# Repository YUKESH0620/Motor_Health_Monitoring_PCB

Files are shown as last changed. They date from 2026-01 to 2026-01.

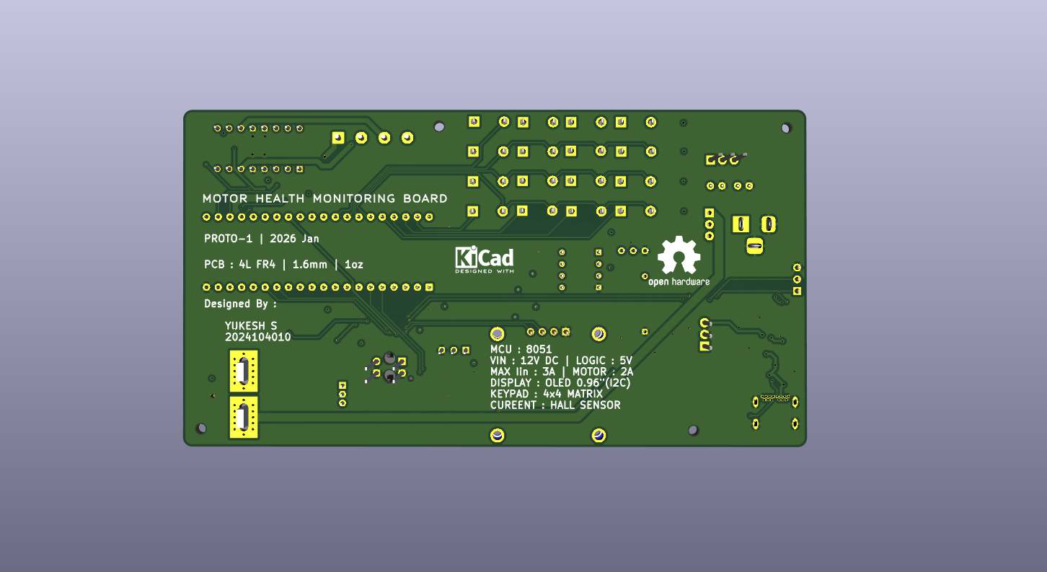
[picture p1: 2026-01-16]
HARDWARE/PCB Layout/3D View images/Screenshot 2026-01-16 144549.png

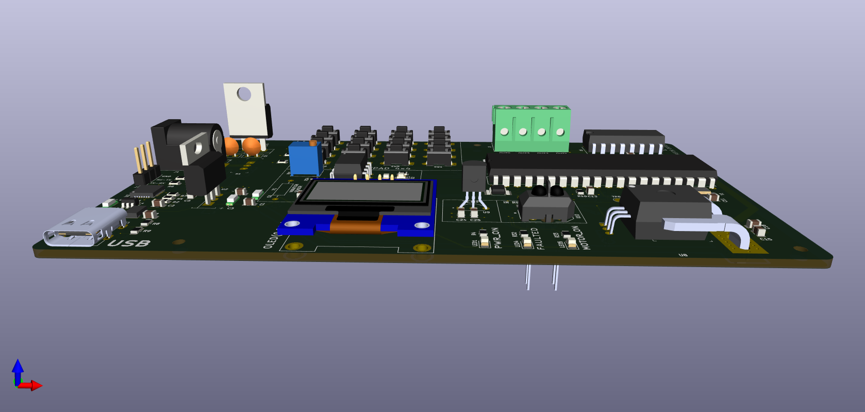
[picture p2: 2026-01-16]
HARDWARE/PCB Layout/3D View images/Screenshot 2026-01-16 144806.png

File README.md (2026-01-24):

# Motor Health Monitoring System using 8051

**Embedded Hardware–Firmware Co-Design Project**

---

## Project Overview

The **Motor Health Monitoring System** is an embedded systems project designed to monitor the operational health of an electric motor and protect it from unsafe conditions.

The project integrates:

* A structured hardware design
* Bare-metal embedded control logic
* Simulation-based validation
* Professional documentation practices

The focus is on **learning, reliability, and design clarity**, following workflows commonly used in industry and academia.

---

## System Purpose

* Monitor key motor parameters
* Detect abnormal operating conditions
* Automatically disable the motor under fault
* Provide clear visual and UART-based feedback
* Enable validation without physical hardware

---

## System Operation Flow

* System initialization

* Peripheral setup

* Sensor sampling

* Data filtering

* Threshold comparison

* Fault decision

* Motor control update

* Display & UART update

* Continuous monitoring loop

## Block Diagram

```
Power Input
    │
    V
Voltage Regulation
    │
    V
Microcontroller (8051)
 |--> Sensor Interface
 |   |--> Current
 |   |--> Temperature
 |   |--> Vibration
 |   |--> IR Sensor
 |
 |--> Motor Driver (PWM Control)
 |--> Display (OLED)
 |--> Keypad Interface
 |--> UART Debug Interface
```

---

## System Summary

| Aspect | Description |
| --- | --- |
| Controller | AT89C51 (8051 architecture) |
| Control Method | Bare-metal |
| Sensors | Current, Temperature, Vibration, IR |
| Motor Control  | PWM-based with fault shutdown |
| Display | OLED (I²C) |
| User Input | 4×4 Keypad |
| Communication  | UART |
| Validation | Proteus Simulation |
| PCB Status | Not fabricated |

---

## Design Artifacts

The repository contains:

* Complete hardware schematics

* PCB layout and 3D models (design stage)

* Proteus simulation files

* Modular firmware source code

* Structured documentation

---

# Schematic Diagram







# PCB Layout





# 3D PCB View









---

## Electrical Specifications

| Parameter | Value |
|---|---|
| Supply Voltage | 5 V DC |
| MCU Logic Level | 5 V |
| Over-Current Threshold | 15 A |
| Over-Temperature Threshold | 70 °C |
| Communication Baud Rate | Configurable (UART) |
| Fault Response Time | Deterministic (loop-based) |

---

# Simulation_v1

The system was simulated using **Proteus 8.1 Professional software** to validate firmware behavior and system-level logic prior to hardware availability.
The AT89C51 microcontroller, UART interface, motor control logic, fault indicators, and peripheral connections were instantiated according to the schematic.

## Proteus Schematic


Sensor inputs were emulated using adjustable sources to exercise overcurrent and overtemperature fault paths. UART output was used to confirm firmware execution flow and system state transitions. Motor operation was verified logically through enable signals and status indicators rather than physical motor dynamics.

Due to simulator limitations with mixed-signal SPI peripherals on the 8051 core, ADC behavior was validated at firmware logic level. Electrical accuracy of sensor interfaces is planned for validation on physical hardware.

---

## Validation Strategy

* Firmware behavior validated using Proteus simulation at system and logic level

* UART used as the primary observation and debug interface to confirm system states

* Motor control and global shutdown behavior verified through control signals and status indicators

* Fault detection, latching, and recovery logic validated against defined thresholds

* Sensor behavior emulated to exercise fault paths; ADC interface validated at firmware logic level

* Simulation limitations identified and documented; full electrical validation planned on physical hardware

* No dependency on physical PCB availability for firmware and system-level validation

---

## Repository Organization

* **Hardware**
  Contains schematic, PCB, simulation files, and hardware documentation

* **Firmware**
  Contains source code, configuration files, and firmware documentation

Each section includes its own detailed README.

---

## Current Project Status

*  Requirements defined
*  Hardware designed
*  Simulation validated
*  Firmware structured and built
*  PCB fabrication pending

---

## Future Enhancements

* Physical PCB manufacturing
* Bench testing with real motors
* Data logging and diagnostics
* IoT expansion via external gateway
* Advanced fault analytics

---

## Author

**YUKESH**
B.E. Electrical and Electronics Engineering

---

## License

This project is intended for **educational and non-commercial use**.
All materials are shared to support learning, experimentation, and academic review.

---

## Closing Note

This project demonstrates a **complete embedded system lifecycle** - from concept and schematic design to firmware integration and simulation-based validation - following practices aligned with real-world engineering workflows.

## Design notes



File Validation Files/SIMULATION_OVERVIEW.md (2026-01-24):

# Simulation Overview

## Purpose
Simulation was used to validate firmware execution, control flow,
and safety logic before hardware availability.

## Scope
* Firmware behavior verification
* Fault detection and latching logic
* Motor enable and shutdown behavior
* UART-based system observation

## Method
* Proteus schematic instantiated per design
* Sensor inputs emulated conceptually
* System behavior observed via UART and GPIO indicators

## Outcome
Simulation successfully validated system-level logic and safety behavior,
with electrical validation deferred to hardware testing.

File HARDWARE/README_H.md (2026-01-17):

# Hardware Design – Motor Health Monitoring System

## Overview

This repository documents the **complete hardware design** of the **Motor Health Monitoring System**.
The system is built around an **AT89C51 (8051) microcontroller** and integrates sensing, motor control, user interaction, communication, and power management blocks.

The hardware has been **fully designed and validated using Proteus simulation**.
At the time of writing, **no physical PCB has been fabricated**.

---

## Hardware Design Objectives

* Reliable motor parameter sensing
* Safe motor drive with immediate shutdown under fault conditions
* Deterministic digital and analog signal routing
* Modular and expandable circuit structure
* Educational clarity aligned with industry practices

---

## System-Level Hardware Architecture

The system is divided into the following functional blocks:

* Power input and regulation
* Microcontroller core
* Motor driver and PWM enable control
* Sensor interface block
* Display and user interface
* Communication and debug interface
* Status indication LEDs
* Test points for validation

---

## Power Architecture

### Power Sources

* **USB power input** (logic power and debugging)
* **External 12V input** (motor supply)

### Regulation

* **7805 Linear Voltage Regulator**

  * Input: 12V
  * Output: +5V (MCU and peripherals)
* Decoupling capacitors:

  * 0.1µF (high-frequency noise suppression)
  * 10µF (bulk stabilization)
* Capacitors placed close to the regulator and IC power pins

### Power Distribution

* +5V rail for MCU, sensors, OLED, and logic circuits
* Motor supply isolated through the motor driver
* Common ground reference across all hardware blocks

---

## Microcontroller Core

### MCU

* **AT89C51 (8051 family)**
* External **12 MHz crystal oscillator**
* RC-based reset network
* **EA pin tied HIGH** to enable internal program memory

### Key Responsibilities

* Sensor data acquisition
* Fault detection and latching
* PWM generation for motor speed control
* Display updates and UART communication
* Global motor enable/disable control

---

## Motor Driver and Control

### Motor Driver

* **L293D Dual H-Bridge Motor Driver**
* Separate logic and motor supply pins
* Internal flyback diode protection

### PWM Enable Circuit

* PWM signals generated by the MCU
* Enable pins routed via pull-up and series resistors
* Allows:

  * Speed control
  * Immediate motor shutdown during faults

### Protection Strategy

* Any detected fault disables the motor globally
* Fault condition remains latched until system reset

---

## Sensor Interface Block

### Current Sensor

* **ACS712 Hall-Effect Current Sensor**
* Measures motor current
* Analog output routed to ADC
* Used for overcurrent fault detection

### Temperature Sensor

* **LM35 Precision Temperature Sensor**
* Linear analog output (10 mV/°C)
* Used for thermal protection

### Vibration Sensor

* **SW-420 Vibration Sensor Module**
* Comparator-based digital output
* Detects abnormal mechanical vibrations

### IR Reflective Sensor

* Used for speed or object detection
* Digital output connected to MCU GPIO

---

## Analog-to-Digital Conversion

* External ADC used for analog sensor interfacing
* Supports multiple sensor channels
* SPI-like digital communication with MCU
* Improves measurement accuracy and noise immunity

---

## Display Interface

### OLED Display

* **0.96-inch SSD1306 OLED**
* I²C communication protocol
* Displays:

  * Motor status
  * Fault information
  * Sensor readings
* External pull-up resistors used on SDA and SCL lines

---

## User Interface

### Keypad

* **4×4 Matrix Keypad**
* Row-column scanning technique
* External pull-up resistors provided
* Used for:

  * Menu navigation
  * Manual reset
  * Parameter selection

---

## Communication Interfaces

### UART Debug Port

* TTL-level UART interface
* Used for:

  * Debug logging
  * Sensor monitoring
  * Fault reporting
* Compatible with USB–TTL converters

### USB Interface

* USB module used for power and communication support
* Includes basic filtering and ESD protection

---

## Status Indication LEDs

* Power ON indicator
* Motor ON indicator
* Fault indicator
* Series resistors selected to limit LED current safely

---

## Test Points and Debug Support

Dedicated test points are provided for:

* Power rails
* UART TX and RX
* PWM outputs
* Sensor signals

These enable:

* Easy probing during simulation
* Oscilloscope-based validation
* Logic analyzer connections

---

## Simulation and Validation

* Complete schematic simulated in **Proteus**
* Sensor behavior emulated
* Fault conditions injected intentionally
* UART monitored using a virtual terminal
* Motor behavior verified at logic level

---

## Design Status

*  Schematic completed
*  Proteus simulation validated
*  Electrical logic verified
*  PCB fabrication not performed

---

## Notes

This hardware design prioritizes:

* Clarity over unnecessary complexity
* Educational transparency
* Industry-relevant schematic practices
* Expandability for future enhancements

---

* **Author:** Yukesh
* **Domain:** Embedded Systems | Motor Control | Hardware–Firmware Co-Design
* **Target MCU:** AT89C51 (8051 Family)

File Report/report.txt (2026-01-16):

Plotted to 'C:\KiCad\Motor_Health_Monitoring005\Motor_Health_Monitoring_PCB-F_Cu.gbr'.
Plotted to 'C:\KiCad\Motor_Health_Monitoring005\Motor_Health_Monitoring_PCB-In1_Cu.gbr'.
Plotted to 'C:\KiCad\Motor_Health_Monitoring005\Motor_Health_Monitoring_PCB-In2_Cu.gbr'.
Plotted to 'C:\KiCad\Motor_Health_Monitoring005\Motor_Health_Monitoring_PCB-B_Cu.gbr'.
Plotted to 'C:\KiCad\Motor_Health_Monitoring005\Motor_Health_Monitoring_PCB-F_Paste.gbr'.
Plotted to 'C:\KiCad\Motor_Health_Monitoring005\Motor_Health_Monitoring_PCB-B_Paste.gbr'.
Plotted to 'C:\KiCad\Motor_Health_Monitoring005\Motor_Health_Monitoring_PCB-F_Silkscreen.gbr'.
Plotted to 'C:\KiCad\Motor_Health_Monitoring005\Motor_Health_Monitoring_PCB-B_Silkscreen.gbr'.
Plotted to 'C:\KiCad\Motor_Health_Monitoring005\Motor_Health_Monitoring_PCB-F_Mask.gbr'.
Plotted to 'C:\KiCad\Motor_Health_Monitoring005\Motor_Health_Monitoring_PCB-B_Mask.gbr'.
Plotted to 'C:\KiCad\Motor_Health_Monitoring005\Motor_Health_Monitoring_PCB-Edge_Cuts.gbr'.
Created Gerber job file 'C:\KiCad\Motor_Health_Monitoring005\Motor_Health_Monitoring_PCB-job.gbrjob'.
Info: Done.
Info: Done.

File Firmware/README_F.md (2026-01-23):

# Motor Health Monitoring System – Firmware

## Overview

This firmware is developed for an 8051-based Motor Health Monitoring System.

It monitors motor current and temperature, controls motor operation via PWM,

and provides fault protection with UART, keypad, and OLED interfaces.

The firmware is designed to be **hardware-independent during development**

and supports **simulation-based validation** prior to PCB manufacturing.

---

## Features

- Motor control using PWM

- Overcurrent and overtemperature protection

- Fault latch mechanism

- UART command interface

- 4×4 keypad control

- OLED (SSD1306) display support

- Simulation mode for pre-hardware testing

---

## Firmware Architecture

Firmware/

|--> Core/ --> main loop, system init

|--> Drivers/ --> UART, ADC, Timer, PWM, GPIO, Keypad

|--> Application/ --> motor state, fault logic, command handling

|--> Middleware/ --> OLED driver

|--> Utils/ --> filtering, delay, numeric print helpers

|--> Config/ --> pin and threshold configuration

|--> Debug/ --> reserved for logging (currently empty)

|--> Docs/ --> flowchart, protocol, fault table

|--> sdcc\_build/ --> SDCC build scripts

---

## System States

- **IDLE**  : Motor stopped, safe state

- **RUN**   : Motor running with PWM control

- **FAULT** : Motor disabled due to fault (latched)

---

## Build Environment

- Compiler: SDCC (mcs51)

- Target MCU: AT89C51

- Build Method: `build.bat`

- Output: `motor\_health\_fw.ihx`

---

## Simulation Mode

This firmware supports simulation mode to validate logic without hardware.

Simulated features:

- ADC values

- Fault injection

- UART command handling

- OLED content updates

This allows full firmware validation before PCB manufacturing.

---

## Reserved Hardware Signals

The IR sensor output and vibration sensor digital output are present
in the hardware design but intentionally unused in firmware v1.0.
They are reserved for future safety and diagnostic enhancements.

These signals are not part of the current fault detection logic
to avoid false triggers and ensure deterministic motor protection.

---

## Notes

- Hardware testing will be performed after PCB fabrication

- Firmware is structured for easy extension and maintenance

- Code is written to be portable and standards-compliant

---

## Author

Motor Health Monitoring System  

Firmware by Yukesh

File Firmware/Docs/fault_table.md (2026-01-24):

## FAULT TABLE - MOTOR HEALTH MONITORING SYSTEM
```
----------------------------------------------------------
Fault Name        : Overcurrent (OC)
Sensor            : ACS770
Threshold         : 15 A
Detection Type    : Instantaneous
Latch             : YES
Recovery          : RESET command / RESET key
Action Taken      :
  - Motor PWM disabled
  - Fault LED ON
  - System state = FAULT
----------------------------------------------------------

----------------------------------------------------------
Fault Name        : Overtemperature (OT)
Sensor            : LM35
Threshold         : 70 °C
Detection Type    : Instantaneous
Latch             : YES
Recovery          : RESET command / RESET key
Action Taken      :
  - Motor PWM disabled
  - Fault LED ON
  - System state = FAULT
----------------------------------------------------------
```
----------------------------------------------------------
Reserved Signals (Not Used in v1.0)
----------------------------------------------------------
IR sensor digital output and vibration sensor D0 output
are present in hardware but are not used for fault detection
in firmware v1.0.

Reason:
- Digital vibration thresholds are noisy
- IR detection is application-dependent
- Current and temperature provide deterministic protection

These signals are reserved for future diagnostic features.

----------------------------------------------------------
Global Fault Behavior
----------------------------------------------------------
- Fault is global (single current sensor)
- Both motors are disabled on any fault
- Fault remains latched until RESET
- START command ignored during FAULT state
----------------------------------------------------------

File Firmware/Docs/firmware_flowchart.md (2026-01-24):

```
POWER ON / RESET
        |
        v
System_Init()
GPIO_Init()
Timer_Init()
UART_Init()
PWM_Init()
Keypad_Init()
OLED_Init()
        |
        v
STATE = IDLE
Motor PWM = 0%
Fault_Latched = NO
        |
        v
---------------- MAIN LOOP ----------------
        |
        v
UART_RX_Process()
Keypad_Scan()
        |
        v
Is START command / key pressed?
        |
       YES
        |
        v
Is Fault_Latched?
        |
       NO
        |
        v
STATE = RUN
Motor PWM = Last_Set_Value
        |
        v
------------------------------------------
        |
        v
Read Sensors
(ADC Current, ADC Temperature)
        |
        v
Convert ADC -> Voltage
Convert Voltage -> Physical Units
        |
        v
Check Fault Conditions
(Current > OC_LIMIT?)
(Temperature > OT_LIMIT?)
        |
        v
If FAULT DETECTED
        |
        v
Fault_Latched = YES
STATE = FAULT
Motor PWM = 0%
Fault LED = ON
        |
        v
------------------------------------------
        |
        v
If RESET command / key pressed
        |
        v
Clear Fault_Latched
STATE = IDLE
Motor PWM = 0%
        |
        v
------------------------------------------
        |
        v
Update OLED Display
(State, PWM %, Current, Temp)
        |
        v
Repeat MAIN LOOP

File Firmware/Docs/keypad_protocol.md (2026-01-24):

## KEYPAD PROTOCOL – MOTOR HEALTH MONITORING SYSTEM

- Keypad Type : 4 × 4 Matrix Keypad
- Interface   : GPIO (Row–Column Scanning)
- MCU         : AT89C51

--------------------------------------------------
HARDWARE CONNECTION
--------------------------------------------------

Rows (Outputs):
```
 R1 → P0.0
 R2 → P0.1
 R3 → P0.2
 R4 → P0.3
```
Columns (Inputs with pull-up resistors):
```
 C1 → P0.4
 C2 → P0.5
 C3 → P0.6
 C4 → P0.7
```
Active Logic:
- Columns are pulled HIGH by resistors
- Key press pulls corresponding column LOW
- Row driven LOW sequentially during scan

--------------------------------------------------
KEY FUNCTION MAPPING
--------------------------------------------------

Key numbering follows logical order returned by firmware
(1 to 16).

Row 1:
--------------------------------------------------
```
Key 1  | START MOTOR
Key 2  | STOP MOTOR
Key 3  | RESET FAULT
Key 4  | EMERGENCY STOP
```
Row 2:
--------------------------------------------------
```
Key 5  | PWM +5%
Key 6  | PWM −5%
Key 7  | PWM +10%
Key 8  | PWM −10%
```
Row 3:
--------------------------------------------------
```
Key 9  | PWM = 25%
Key 10 | PWM = 50%
Key 11 | PWM = 75%
Key 12 | PWM = 100%
```
Row 4:
--------------------------------------------------
```
Key 13 | Reserved (Future use)
Key 14 | Reserved (Future use)
Key 15 | Reserved (Future use)
Key 16 | Reserved (Future use)
```
--------------------------------------------------
FUNCTIONAL RULES
--------------------------------------------------

- START is ignored if a fault is latched
- RESET clears fault latch and returns system to IDLE
- PWM keys are effective only in RUN state
- EMERGENCY STOP immediately disables motor PWM
- Fault state overrides all keypad inputs except RESET

--------------------------------------------------
DEBOUNCE POLICY
--------------------------------------------------

- Software debounce implemented
- Key must be released before next detection
- Long press is treated as single press

--------------------------------------------------
NOTES
--------------------------------------------------

- Keypad control and UART control operate in parallel
- Both interfaces follow the same state machine rules
- Keypad is intended for local/manual control

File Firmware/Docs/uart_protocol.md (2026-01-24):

## UART PROTOCOL - MOTOR HEALTH MONITORING SYSTEM
```
Baud Rate   : 9600
Data Bits   : 8
Parity      : None
Stop Bits   : 1
Line Ending : LF (\n)
Case        : Case-insensitive
Echo        : Enabled
```
-----------------------------------------
COMMAND LIST
-----------------------------------------

START
- Action: Start motor
- Condition: Only if no fault is latched
- Response: OK:RUN

STOP
- Action: Stop motor
- Response: OK:IDLE

RESET
- Action: Clear fault latch and go to IDLE
- Response: OK:RESET

PWM <0–100>
- Action: Set PWM duty cycle percentage
- Example: PWM 60
- Response: OK:PWM=60

STATUS
- Action: Report current system status
- Response Format:
  ```
  STATE=<IDLE/RUN/FAULT>
  PWM=<value>
  I=<current_A>
  T=<temperature_C>
  ```
-----------------------------------------
ERROR RESPONSES
-----------------------------------------

- ERR:FAULT_ACTIVE
- ERR:INVALID_CMD
- ERR:OUT_OF_RANGE

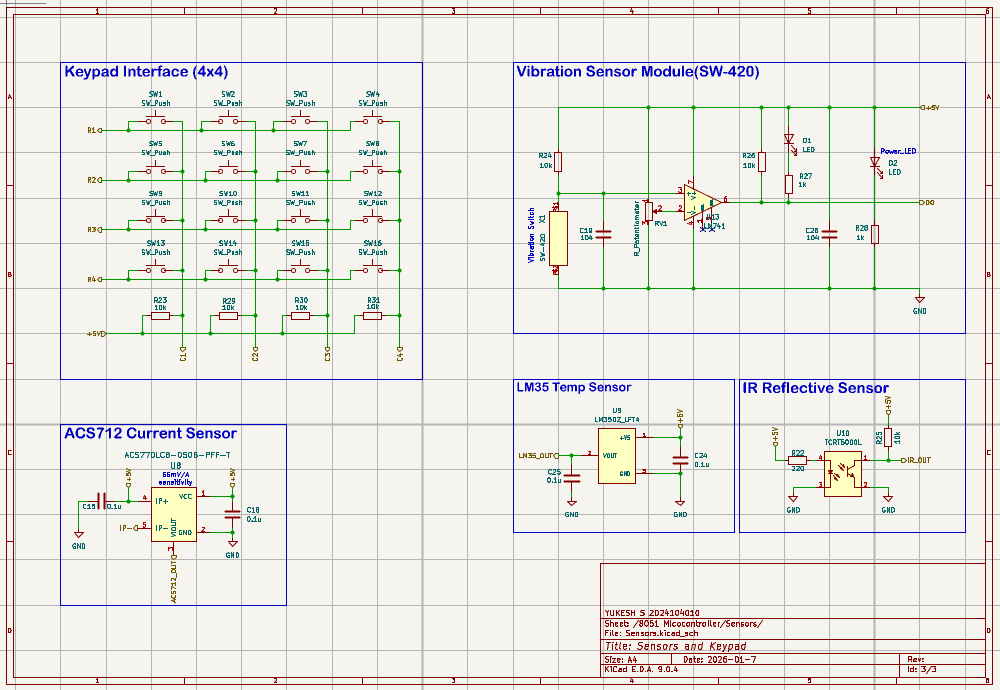
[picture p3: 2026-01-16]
Images/Schematic images/Screenshot 2026-01-11 205225.png

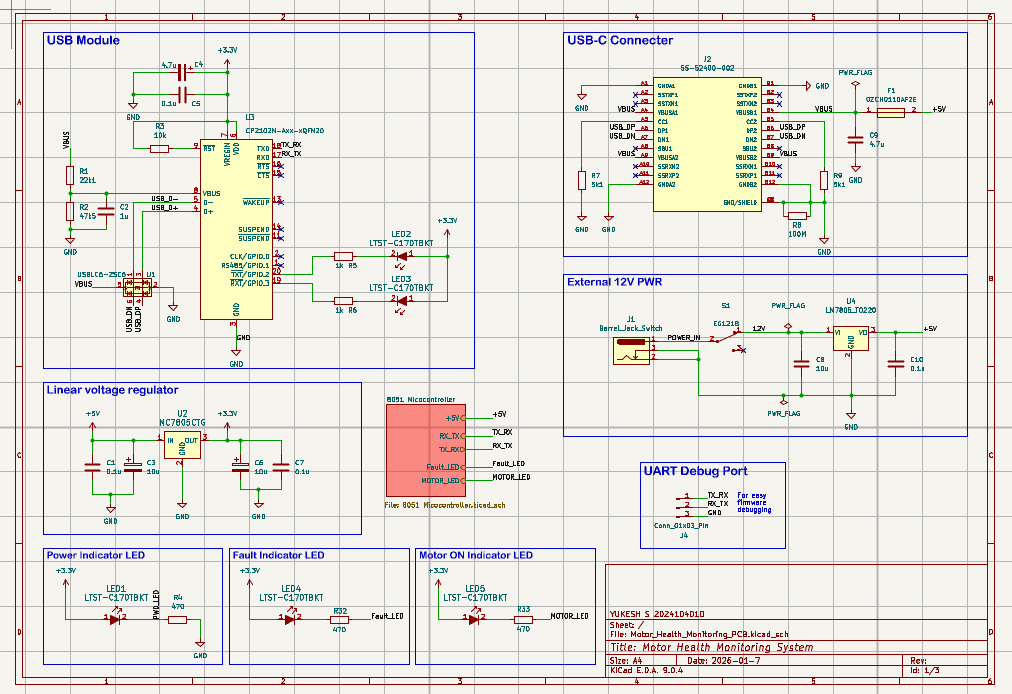
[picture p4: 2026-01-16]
Images/Schematic images/Screenshot 2026-01-11 205045 - Copy.png

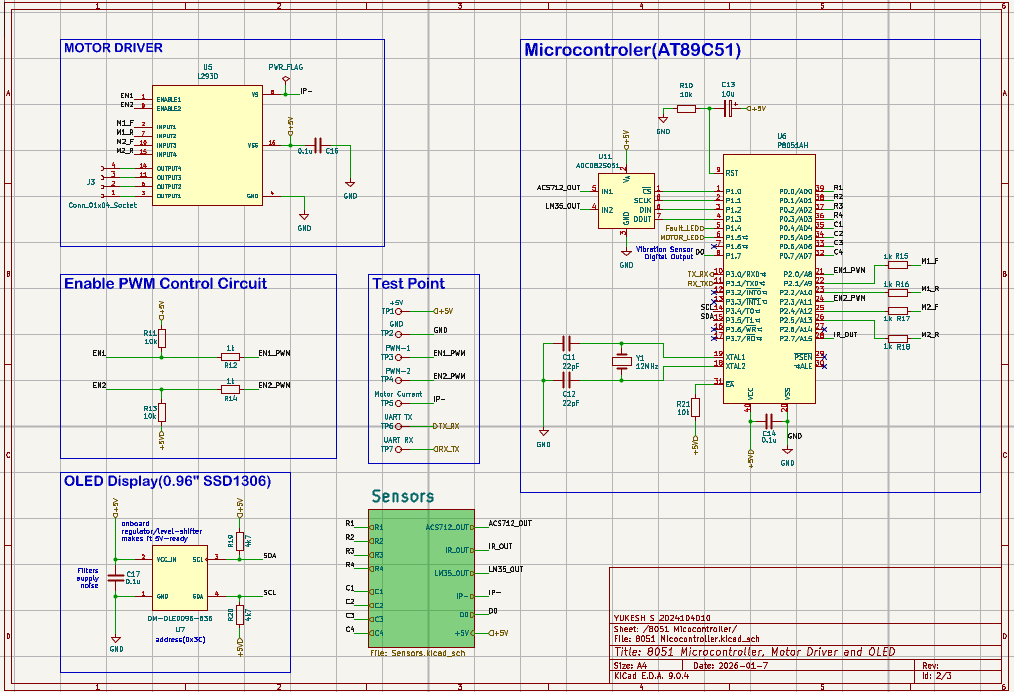
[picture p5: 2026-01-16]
Images/Schematic images/Screenshot 2026-01-11 205103 - Copy (2).png

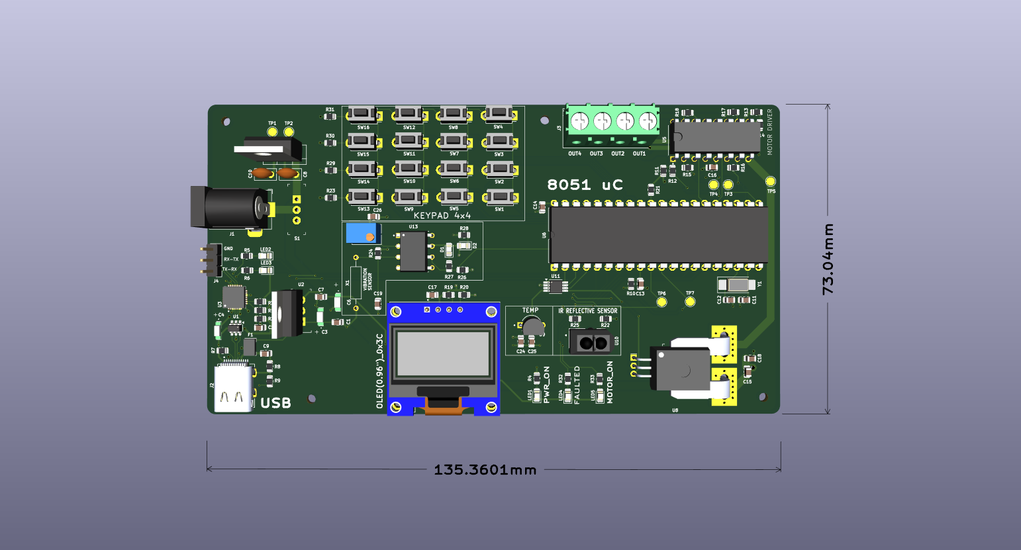
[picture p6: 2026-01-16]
HARDWARE/PCB Layout/3D View images/Screenshot 2026-01-16 144525.png

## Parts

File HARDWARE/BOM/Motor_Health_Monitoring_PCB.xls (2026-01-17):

Reference | Value | Qty | Description | Footprint | Purpose | Datasheet
C1 | 0.1u | 1 | Unpolarized capacitor | Capacitor_SMD:C_0805_2012Metric |  | ~
C2 | 1u | 1 | Unpolarized capacitor | Capacitor_SMD:C_0805_2012Metric |  | ~
C3 | 10u | 1 | Polarized capacitor | Esp-32_sensor_Board004_Footprints:T491A |  | ~
C4 | 4.7u | 1 | Polarized capacitor | Esp-32_sensor_Board004_Footprints:T491A |  | ~
C5 | 0.1u | 1 | Unpolarized capacitor | Capacitor_SMD:C_0805_2012Metric |  | ~
C6 | 10u | 1 | Polarized capacitor | Esp-32_sensor_Board004_Footprints:T491A |  | ~
C7 | 0.1u | 1 | Unpolarized capacitor | Capacitor_SMD:C_0805_2012Metric |  | ~
C8 | 10u | 1 | Unpolarized capacitor | Capacitor_THT:C_Disc_D5.0mm_W2.5mm_P2.50mm |  | ~
C9 | 4.7u | 1 | Unpolarized capacitor | Capacitor_SMD:C_0805_2012Metric |  | ~
C10 | 0.1u | 1 | Unpolarized capacitor | Capacitor_THT:C_Disc_D5.0mm_W2.5mm_P2.50mm |  | ~
C11 | 22pF | 1 | Unpolarized capacitor | Capacitor_SMD:C_0805_2012Metric |  | ~
C12 | 22pF | 1 | Unpolarized capacitor | Capacitor_SMD:C_0805_2012Metric |  | ~
C13 | 10u | 1 | Polarized capacitor | Capacitor_SMD:C_0805_2012Metric |  | ~
C14 | 0.1u | 1 | Unpolarized capacitor | Capacitor_SMD:C_0805_2012Metric |  | ~
C15 | 0.1u | 1 | Unpolarized capacitor | Capacitor_SMD:C_0805_2012Metric |  | ~
C16 | 0.1u | 1 | Unpolarized capacitor | Capacitor_SMD:C_0805_2012Metric |  | ~
C17 | 0.1u | 1 | Unpolarized capacitor | Capacitor_SMD:C_0805_2012Metric |  | ~
C18 | 0.1u | 1 | Unpolarized capacitor | Capacitor_SMD:C_0805_2012Metric |  | ~
C19 | 104 | 1 | Unpolarized capacitor | Capacitor_SMD:C_0805_2012Metric |  | ~
C24 | 0.1u | 1 | Unpolarized capacitor | Capacitor_SMD:C_0805_2012Metric |  | ~
C25 | 0.1u | 1 | Unpolarized capacitor | Capacitor_SMD:C_0805_2012Metric |  | ~
C26 | 104 | 1 | Unpolarized capacitor | Capacitor_SMD:C_0805_2012Metric |  | ~
D1 | LED | 1 | Light emitting diode | LED_SMD:LED_0805_2012Metric_Pad1.15x1.40mm_HandSolder |  | ~
D2 | LED | 1 | Light emitting diode | LED_SMD:LED_0805_2012Metric_Pad1.15x1.40mm_HandSolder |  | ~
F1 | 0ZCH0110AF2E | 1 | 1210 SMT PPTC | 1.10 Ih | 16V | Esp-32_sensor_Board004_Footprints:FUSC3226X100N |  | https://www.belfuse.com/resources/datasheets/circuitprotection/ds-cp-0zch-series.pdf
J1 | Barrel_Jack_Switch | 1 | DC Barrel Jack with an internal switch | Connector_BarrelJack:BarrelJack_Horizontal |  | ~
J2 | SS-52400-002 | 1 | USB-C Connector | Esp-32_sensor_Board004_Footprints:BELFUSE_SS-52400-002
J3 | Conn_01x04_Socket | 1 | Generic connector, single row, 01x04, script generated | Connector_PinHeader_2.54mm:PinHeader_1x04_P2.54mm_Horizontal |  | ~
J4 | Conn_01x03_Pin | 1 | Generic connector, single row, 01x03, script generated | Connector_PinHeader_2.54mm:PinHeader_1x03_P2.54mm_Horizontal |  | ~
LED1 | LTST-C170TBKT | 1 | LED BLUE CLEAR SMD | LED_SMD:LED_0805_2012Metric_Pad1.15x1.40mm_HandSolder |  | http://optoelectronics.liteon.com/upload/download/DS-22-99-0226/LTST-C170TBKT.pdf
LED2 | LTST-C170TBKT | 1 | LED BLUE CLEAR SMD | LED_SMD:LED_0805_2012Metric_Pad1.15x1.40mm_HandSolder |  | http://optoelectronics.liteon.com/upload/download/DS-22-99-0226/LTST-C170TBKT.pdf
LED3 | LTST-C170TBKT | 1 | LED BLUE CLEAR SMD | LED_SMD:LED_0805_2012Metric_Pad1.15x1.40mm_HandSolder |  | http://optoelectronics.liteon.com/upload/download/DS-22-99-0226/LTST-C170TBKT.pdf
LED4 | LTST-C170TBKT | 1 | LED BLUE CLEAR SMD | LED_SMD:LED_0805_2012Metric_Pad1.15x1.40mm_HandSolder |  | http://optoelectronics.liteon.com/upload/download/DS-22-99-0226/LTST-C170TBKT.pdf
LED5 | LTST-C170TBKT | 1 | LED BLUE CLEAR SMD | LED_SMD:LED_0805_2012Metric_Pad1.15x1.40mm_HandSolder |  | http://optoelectronics.liteon.com/upload/download/DS-22-99-0226/LTST-C170TBKT.pdf
R1 | 22k1 | 1 | Resistor | Resistor_SMD:R_0805_2012Metric |  | ~
R2 | 47k5 | 1 | Resistor | Resistor_SMD:R_0805_2012Metric |  | ~
R3 | 10k | 1 | Resistor | Resistor_SMD:R_0805_2012Metric |  | ~
R4 | 470 | 1 | Resistor | Resistor_SMD:R_0805_2012Metric |  | ~
R5 | 1k | 1 | Resistor | Resistor_SMD:R_0805_2012Metric |  | ~
R6 | 1k | 1 | Resistor | Resistor_SMD:R_0805_2012Metric |  | ~
R7 | 5k1 | 1 | Resistor | Resistor_SMD:R_0805_2012Metric |  | ~
R8 | 100M | 1 | Resistor | Resistor_SMD:R_0805_2012Metric |  | ~
R9 | 5k1 | 1 | Resistor | Resistor_SMD:R_0805_2012Metric |  | ~
R10 | 10k | 1 | Resistor | Resistor_SMD:R_0805_2012Metric |  | ~
R11 | 10k | 1 | Resistor | Resistor_SMD:R_0805_2012Metric |  | ~
R12 | 1k | 1 | Resistor | Resistor_SMD:R_0805_2012Metric |  | ~
R13 | 10k | 1 | Resistor | Resistor_SMD:R_0805_2012Metric |  | ~
R14 | 1k | 1 | Resistor | Resistor_SMD:R_0805_2012Metric |  | ~
R15 | 1k | 1 | Resistor | Resistor_SMD:R_0805_2012Metric |  | ~
R16 | 1k | 1 | Resistor | Resistor_SMD:R_0805_2012Metric |  | ~
R17 | 1k | 1 | Resistor | Resistor_SMD:R_0805_2012Metric |  | ~
R18 | 1k | 1 | Resistor | Resistor_SMD:R_0805_2012Metric |  | ~
R19 | 4k7 | 1 | Resistor | Resistor_SMD:R_0805_2012Metric |  | ~
R20 | 4k7 | 1 | Resistor | Resistor_SMD:R_0805_2012Metric |  | ~
R21 | 10k | 1 | Resistor | Resistor_SMD:R_0805_2012Metric |  | ~
R22 | 220 | 1 | Resistor | Resistor_SMD:R_0805_2012Metric |  | ~
R23 | 10k | 1 | Resistor | Resistor_SMD:R_0805_2012Metric |  | ~
R24 | 10k | 1 | Resistor | Resistor_SMD:R_0805_2012Metric |  | ~
R25 | 10k | 1 | Resistor | Resistor_SMD:R_0805_2012Metric |  | ~
R26 | 10k | 1 | Resistor | Resistor_SMD:R_0805_2012Metric |  | ~
R27 | 1k | 1 | Resistor | Resistor_SMD:R_0805_2012Metric |  | ~
R28 | 1k | 1 | Resistor | Resistor_SMD:R_0805_2012Metric |  | ~
R29 | 10k | 1 | Resistor | Resistor_SMD:R_0805_2012Metric |  | ~
R30 | 10k | 1 | Resistor | Resistor_SMD:R_0805_2012Metric |  | ~
R31 | 10k | 1 | Resistor | Resistor_SMD:R_0805_2012Metric |  | ~
R32 | 470 | 1 | Resistor | Resistor_SMD:R_0805_2012Metric |  | ~
R33 | 470 | 1 | Resistor | Resistor_SMD:R_0805_2012Metric |  | ~
RV1 | R_Potentiometer | 1 | Potentiometer | Potentiometer_THT:Potentiometer_Bourns_3266Y_Vertical |  | ~
S1 | EG1218 | 1 | SWITCH SLIDE SPDT 200MA 30V | digikey-footprints:Switch_Slide_11.6x4mm_EG1218 |  | http://spec_sheets.e-switch.com/specs/P040040.pdf
SW1 | SW_Push | 1 | Push button switch, generic, two pins | Button_Switch_THT:SW_PUSH_1P1T_6x3.5mm_H5.0_APEM_MJTP1250 |  | ~
SW2 | SW_Push | 1 | Push button switch, generic, two pins | Button_Switch_THT:SW_PUSH_1P1T_6x3.5mm_H5.0_APEM_MJTP1250 |  | ~
SW3 | SW_Push | 1 | Push button switch, generic, two pins | Button_Switch_THT:SW_PUSH_1P1T_6x3.5mm_H5.0_APEM_MJTP1250 |  | ~
SW4 | SW_Push | 1 | Push button switch, generic, two pins | Button_Switch_THT:SW_PUSH_1P1T_6x3.5mm_H5.0_APEM_MJTP1250 |  | ~
SW5 | SW_Push | 1 | Push button switch, generic, two pins | Button_Switch_THT:SW_PUSH_1P1T_6x3.5mm_H5.0_APEM_MJTP1250 |  | ~
SW6 | SW_Push | 1 | Push button switch, generic, two pins | Button_Switch_THT:SW_PUSH_1P1T_6x3.5mm_H5.0_APEM_MJTP1250 |  | ~
SW7 | SW_Push | 1 | Push button switch, generic, two pins | Button_Switch_THT:SW_PUSH_1P1T_6x3.5mm_H5.0_APEM_MJTP1250 |  | ~
SW8 | SW_Push | 1 | Push button switch, generic, two pins | Button_Switch_THT:SW_PUSH_1P1T_6x3.5mm_H5.0_APEM_MJTP1250 |  | ~
SW9 | SW_Push | 1 | Push button switch, generic, two pins | Button_Switch_THT:SW_PUSH_1P1T_6x3.5mm_H5.0_APEM_MJTP1250 |  | ~
SW10 | SW_Push | 1 | Push button switch, generic, two pins | Button_Switch_THT:SW_PUSH_1P1T_6x3.5mm_H5.0_APEM_MJTP1250 |  | ~
SW11 | SW_Push | 1 | Push button switch, generic, two pins | Button_Switch_THT:SW_PUSH_1P1T_6x3.5mm_H5.0_APEM_MJTP1250 |  | ~
SW12 | SW_Push | 1 | Push button switch, generic, two pins | Button_Switch_THT:SW_PUSH_1P1T_6x3.5mm_H5.0_APEM_MJTP1250 |  | ~
SW13 | SW_Push | 1 | Push button switch, generic, two pins | Button_Switch_THT:SW_PUSH_1P1T_6x3.5mm_H5.0_APEM_MJTP1250 |  | ~
SW14 | SW_Push | 1 | Push button switch, generic, two pins | Button_Switch_THT:SW_PUSH_1P1T_6x3.5mm_H5.0_APEM_MJTP1250 |  | ~
SW15 | SW_Push | 1 | Push button switch, generic, two pins | Button_Switch_THT:SW_PUSH_1P1T_6x3.5mm_H5.0_APEM_MJTP1250 |  | ~
SW16 | SW_Push | 1 | Push button switch, generic, two pins | Button_Switch_THT:SW_PUSH_1P1T_6x3.5mm_H5.0_APEM_MJTP1250 |  | ~
TP1 | +5V | 1 | test point | TestPoint:TestPoint_Bridge_Pitch2.54mm_Drill1.3mm |  | ~
TP2 | GND | 1 | test point | TestPoint:TestPoint_Bridge_Pitch2.54mm_Drill1.3mm |  | ~
TP3 | PWM-1 | 1 | test point | TestPoint:TestPoint_Bridge_Pitch2.54mm_Drill1.3mm |  | ~
TP4 | PWM-2 | 1 | test point | TestPoint:TestPoint_Bridge_Pitch2.54mm_Drill1.3mm |  | ~
TP5 | Motor Current | 1 | test point | TestPoint:TestPoint_Bridge_Pitch2.54mm_Drill1.3mm |  | ~
TP6 | UART TX | 1 | test point | TestPoint:TestPoint_Bridge_Pitch2.54mm_Drill1.3mm |  | ~
TP7 | UART RX | 1 | test point | TestPoint:TestPoint_Bridge_Pitch2.54mm_Drill1.3mm |  | ~
U1 | USBLC6-2SC6 | 1 | Very low capacitance ESD protection diode, 2 data-line, SOT-23-6 | Package_TO_SOT_SMD:SOT-23-6 |  | https://www.st.com/resource/en/datasheet/usblc6-2.pdf
U2 | MC7805CTG | 1 | IC REG LINEAR 5V 1A TO220AB | digikey-footprints:TO-220-3 |  | http://www.onsemi.com/pub/Collateral/MC7800-D.PDF
U3 | CP2102N-Axx-xQFN20 | 1 | USB to UART master bridge, QFN-20 | Footprints:QFN50P500X500X100-29N |  | https://www.silabs.com/documents/public/data-sheets/cp2102n-datasheet.pdf
U4 | LM7805_TO220 | 1 | Positive 1A 35V Linear Regulator, Fixed Output 5V, TO-220 | Package_TO_SOT_THT:TO-220-3_Vertical |  | https://www.onsemi.cn/PowerSolutions/document/MC7800-D.PDF
U5 | L293D | 1 | Motor Driver 2 Channel | Footprints:DIP880W50P254L2000H510Q16
U6 | P8051AH | 1 | MCS-51 8-bit Control-Oriented Microcontrollers, 4K x 8 masked ROM, 128 x 8 RAM, 2x 16-bit timers / event counters, 12MHz, DIP-40 | Package_DIP:DIP-40_W15.24mm |  | https://www.datasheetarchive.com/datasheet/MCS%2051/Intel
U7 | DM-OLED096-636 | 1 | OLED Display( 0.96" ) | Footprints:MODULE_DM-OLED096-636
U8 | ACS770LCB-050B-PFF-T | 1 | SENSOR CURRENT HALL 50A AC/DC | digikey-footprints:CB-5_Formed_Leads |  | https://www.allegromicro.com/~/media/Files/Datasheets/ACS770-Datasheet.pdf
U9 | LM35DZ_LFT4 | 1 | Temperature Sensor | Footprints:IC_LM35DZ_LFT4
U10 | TCRT5000L | 1 | IR Reflection Detector | Footprints:XDCR_TCRT5000L
U11 | ADC082S051 | 1 | 2 channel, 200 - 500 ksps, 8-bit ADC, 2.7 - 5.25V supply, TSSOP-8 (MSOP-8, Texas VSSOP-8) | Package_SO:VSSOP-8_3x3mm_P0.65mm |  | https://www.ti.com/lit/ds/symlink/adc082s051.pdf
U13 | LM741 | 1 | Operational Amplifier, DIP-8/TO-99-8 | Footprints:DIP794W45P254L959H508Q8 |  | http://www.ti.com/lit/ds/symlink/lm741.pdf
X1 | SW-420 | 1 | Vibration sensor | Footprints:SW-420
Y1 | 12MHz | 1 | Two pin crystal | Crystal:Crystal_SMD_5032-2Pin_5.0x3.2mm_HandSoldering |  | ~

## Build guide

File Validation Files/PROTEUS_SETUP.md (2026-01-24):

# Proteus Setup

## Simulation Tool
* Proteus 8.1 Professional used for system-level simulation

## Core Components
* AT89C51 microcontroller
* Virtual Terminal for UART observation
* GPIO indicators for motor status and fault indication
* Emulated sensor inputs using adjustable sources

## Firmware Integration
* Firmware compiled using SDCC
* Compiled output loaded into MCU program memory
* Clock and reset configured as per schematic

## Usage Notes
* Virtual Terminal must be opened manually during simulation
* Simulation reset used to validate system re-initialization

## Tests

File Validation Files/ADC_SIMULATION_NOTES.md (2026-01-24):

# ADC Simulation Notes

## Overview

The Motor Health Monitoring System uses an external SPI-based ADC to acquire current and temperature sensor data. During the current project phase, ADC behavior was evaluated primarily at the firmware and logic level using Proteus simulation.

This document clarifies the scope, approach, and limitations of ADC validation performed in simulation.

## ADC Interface in Firmware

The ADC is interfaced using bit-banged SPI driven by AT89C51 GPIO pins.

Chip Select (CS) is implemented as an active-low digital control signal.

Clock and data lines are controlled entirely by firmware.

ADC read routines follow correct transaction structure for real hardware operation.

The firmware implementation is considered hardware-correct and suitable for physical validation.

## Sensor Emulation in Simulation

Physical sensors were not electrically simulated.

Adjustable sources (potentiometers) were used to conceptually emulate sensor outputs.

These sources were intended to exercise:

* Overcurrent fault logic
 
* Overtemperature fault logic

The purpose was to validate fault detection, latching, and system response, not analog accuracy.

## Proteus Simulation Limitation

During simulation, it was observed that:

Proteus does not reliably support bit-banged SPI ADC communication with the 8051 core.

The MCP3008 ADC model requires strict protocol timing and framing.

GPIO-driven chip-select and clock signals from the AT89C51 are not consistently recognized by the ADC model.

Forcing chip-select low does not resolve this limitation.

### As a result:

* Real-time ADC value changes could not be reliably observed in simulation.

* This is a tool limitation, not a firmware or design error.

## Validation Scope Achieved

Despite the above limitation, the following were successfully validated:

* Correct firmware structure for ADC access

* Proper chip-select control logic

* Integration of ADC readings into sensor and fault management modules

* Fault triggering, latching, and motor shutdown behavior based on threshold logic

ADC functionality was therefore validated at the firmware logic level.

## Planned Hardware Validation

Full electrical validation of the ADC and sensor interfaces is planned on physical hardware, including:

* Verification of SPI timing

* Sensor voltage-to-physical unit accuracy

* Noise and dynamic behavior under real operating conditions

This will be addressed once the PCB is fabricated and assembled.

## Summary

Proteus simulation was used to validate ADC-related firmware logic and system behavior.

Due to known simulator limitations with mixed-signal SPI peripherals on the 8051 platform, electrical ADC behavior was not validated in simulation. This limitation has been identified, documented, and deferred to the hardware validation phase.

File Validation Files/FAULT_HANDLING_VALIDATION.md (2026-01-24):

# Fault Handling Validation

## Objective

   To validate the correctness of fault detection, latching, and safety response logic implemented in firmware for the Motor Health Monitoring System.

   The validation focuses on system behavior and safety logic, independent of physical hardware availability.

## Faults Implemented

 The firmware implements the following fault conditions:

  1. Overcurrent Fault (OC)

    Sensor: ACS770 (emulated in simulation)

    Threshold: 15 A

    Detection type: Instantaneous

    Latching: Yes

    Recovery: System reset (RESET command / RESET key)

  2. Overtemperature Fault (OT)

    Sensor: LM35 (emulated in simulation)

    Threshold: 70 °C

    Detection type: Instantaneous

    Latching: Yes

    Recovery: System reset (RESET command / RESET key)

## Global Fault Behavior

 The following global behaviors were validated:

 * Fault detection is global (single current and temperature source)

 * Any fault disables all motor outputs

 * Fault condition remains latched until reset

 * START or run commands are ignored during FAULT state

 * Visual fault indication is provided via a dedicated fault LED

## Validation Method

 * Fault logic was exercised using emulated sensor inputs in Proteus.

 * Sensor values were varied conceptually to cross defined thresholds.

 * UART output and LED indicators were used to observe system state transitions.

 * Motor behavior was verified logically through motor enable control signals.

 This approach validates decision-making and safety enforcement, not sensor electrical accuracy.

## Test Scenarios and Observations

 Normal Operation

 * Sensor values below thresholds

 * Motor enable signals active

 * Fault LED OFF

 * System remains in RUN state

 Result: Pass

## Overcurrent Fault Trigger

 * Emulated current exceeds 15 A threshold

 * Fault detected immediately

 Observed behavior:

 * Fault LED ON

 * Motor enable signals disabled

 * Fault state latched

 Result: Pass

## Overtemperature Fault Trigger

 * Emulated temperature exceeds 70 °C threshold

 * Fault detected immediately

 Observed behavior:

 * Fault LED ON

 * Motor enable signals disabled

 * Fault state latched

 Result: Pass

## Fault Latching Verification

 * After fault occurrence, sensor values returned to safe range

 * System remained in FAULT state

 * Motor outputs remained disabled

 Result: Pass

## Fault Recovery

 * System reset issued

 * Fault latch cleared

 * System returned to normal operation

 Result: Pass

## Key Observations

 * Fault handling logic behaves deterministically and safely

 * Motor shutdown is enforced immediately upon fault detection

 * Latching prevents unsafe automatic recovery

 * Visual and control indicators correctly reflect fault state

## Validation Scope and Limitations

 * Fault handling was validated at firmware and system logic level

 * Electrical accuracy of sensors was not validated in simulation

 * Real-world sensor dynamics and noise are deferred to hardware testing

## Conclusion

 Fault detection, latching, and global shutdown behavior were successfully validated using simulation-based logic testing. The implemented fault handling mechanism meets the defined safety requirements and provides a robust foundation for subsequent hardware validation.

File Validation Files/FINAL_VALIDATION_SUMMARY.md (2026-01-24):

# Final Validation Summary

## Validation Scope
* Validation performed prior to physical PCB availability
* Focus on firmware behavior and system-level safety logic
* Simulation used to exercise control flow and fault handling
* Electrical accuracy deferred to hardware phase

## Simulation Environment
* Proteus used for system-level simulation
* AT89C51 microcontroller instantiated per schematic
* UART used as the primary observation interface
* Indicators and control signals used to verify system response

## Firmware Validation Achieved
* Correct firmware execution and startup behavior verified
* State transitions confirmed through UART output
* Motor enable and shutdown logic validated
* Fault latching behavior confirmed
* Reset-based fault recovery verified

## Fault Handling Validation
* Overcurrent fault detected at defined threshold
* Overtemperature fault detected at defined threshold
* Fault behavior is global and disables all motors
* Fault condition remains latched until reset
* Motor restart blocked during fault state

## ADC and Sensor Validation
* ADC interface implemented and reviewed at firmware logic level
* Sensor inputs emulated to exercise fault paths
* ADC behavior could not be electrically validated in simulation
* ADC limitations identified and documented clearly

## Simulation Limitations
* Mixed-signal ADC behavior not reliably simulated with 8051 core
* GPIO-driven serial ADC communication limited by tool constraints
* Real sensor dynamics and noise not modeled
* Motor electrical behavior not simulated

## Overall Assessment
* Core safety and control logic validated successfully
* Firmware architecture confirmed to be stable and modular
* System behavior matches design intent
* Project is ready for physical hardware validation phase

## Next Steps
* PCB fabrication and bring-up
* Electrical validation of ADC and sensors
* Motor load testing under real operating conditions
* Final system integration and field testing

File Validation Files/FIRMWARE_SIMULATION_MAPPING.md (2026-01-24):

# Firmware to Simulation Mapping

## Purpose
This document describes how firmware modules and signals are mapped to
Proteus simulation elements. The intent is to clearly show how firmware
behavior was observed and validated in the absence of physical hardware.

---

## Microcontroller Mapping
* MCU: AT89C51
* Clock frequency configured as per schematic
* Firmware built using SDCC and loaded into Proteus MCU model
* All GPIO usage follows pin_config.h without modification

---

## UART Interface Mapping
* Firmware module: Drivers/uart.c
* MCU pins mapped to Proteus Virtual Terminal
* UART used for:
  * Startup confirmation
  * State indication
  * Debug and observation output
* UART acts as the primary external visibility interface in simulation

---

## Motor Control Mapping
* Firmware modules:
  * Drivers/gpio.c
  * Application/fault_manager.c
* Motor enable signals generated on PWM/enable pins
* In simulation:
  * Motor behavior verified logically
  * Enable/disable action observed via GPIO states and LEDs
* Physical motor dynamics not simulated

---

## Fault Indicator Mapping
* Fault LED mapped directly to MCU GPIO pin
* LED polarity implemented in firmware based on schematic wiring
* Fault LED used to confirm:
  * Fault detection
  * Fault latching
  * Persistent fault state until reset

---

## Sensor Input Mapping
* Firmware module: Application/sensor_manager.c
* Sensor values conceptually provided via simulation inputs
* Potentiometers used to emulate sensor output levels
* Mapping used to exercise:
  * Overcurrent fault logic
  * Overtemperature fault logic
* Electrical sensor accuracy not modeled

---

## ADC Interface Mapping
* Firmware module: Drivers/adc.c
* GPIO-driven serial ADC interface implemented in firmware
* ADC read function integrated into sensor management logic
* In simulation:
  * ADC interface validated at firmware logic level
  * Electrical ADC behavior not reliably observable due to tool limitations

---

## IR Sensor Mapping
* IR sensor treated as a digital input signal
* Logic-level changes used to emulate sensor events
* IR input not part of fault handling path
* Used only for state or event-based logic (if applicable)

---

## Reset and Recovery Mapping
* Firmware reset logic clears fault latch
* Simulation reset used to validate:
  * Fault recovery
  * System re-initialization
* Reset behavior matches intended system design

---

## Summary
* Firmware modules were mapped directly to simulation elements
* Simulation focused on validating control flow and safety behavior
* All mappings reflect intended hardware connections
* Any limitations in electrical behavior are documented separately

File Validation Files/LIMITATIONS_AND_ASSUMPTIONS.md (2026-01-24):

# Limitations and Assumptions

## Assumptions
* Firmware logic is validated independently of physical hardware availability.
* Sensor behavior is emulated conceptually for fault-path validation.
* ADC thresholds are evaluated at firmware logic level
* UART output is considered a reliable indicator of system state
* Motor control is validated via enable signals, not physical motor dynamics

## Simulation Limitations
* Proteus does not reliably support GPIO-driven serial ADC communication with the 8051 core
* Electrical behavior of the ADC could not be observed accurately in simulation
* Real sensor noise, offset, and dynamic behavior are not modeled
* Motor electrical characteristics such as load and inertia are not simulated

## Impact on Validation
* Limitations do not affect validation of control flow or safety logic
* Core system behavior remains verifiable through firmware execution
* Electrical validation is deferred to the hardware testing phase

## Mitigation Strategy
* Firmware designed to be hardware-correct and portable
* Limitations clearly documented to avoid misinterpretation
* Planned hardware validation phase defined for future work

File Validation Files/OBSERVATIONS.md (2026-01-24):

# Observations

## General Observations
* Firmware boots consistently and executes as expected
* UART output confirms correct startup and state transitions
* System enters fault state deterministically when conditions are met

## Fault Behavior
* Overcurrent and overtemperature faults trigger immediately
* Fault state is latched and persists until reset
* Motor enable signals are disabled during fault state
* Visual indicators correctly reflect system condition

## ADC and Sensor Observations
* ADC interface logic functions as intended in firmware
* Sensor emulation sufficient to exercise fault logic
* ADC electrical behavior could not be observed due to simulator constraints

## Simulation Stability
* System remains stable when ADC is treated at logic level
* Extended mixed-signal simulation causes instability
* Best results achieved by focusing on control logic validation

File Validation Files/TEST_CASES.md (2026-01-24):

# Test Cases

## Test Case 1: System Startup
* Condition: Power-on reset
* Expected: UART startup message, no fault
* Result: Pass

## Test Case 2: Normal Operation
* Condition: Sensor values below thresholds
* Expected: Motor enabled, fault LED OFF
* Result: Pass

## Test Case 3: Overcurrent Fault
* Condition: Emulated current exceeds threshold
* Expected: Fault latched, motor disabled
* Result: Pass

## Test Case 4: Overtemperature Fault
* Condition: Emulated temperature exceeds threshold
* Expected: Fault latched, motor disabled
* Result: Pass

## Test Case 5: Fault Latching
* Condition: Sensor values return to safe range after fault
* Expected: System remains in fault state
* Result: Pass

## Test Case 6: Fault Recovery
* Condition: System reset
* Expected: Fault cleared, normal operation restored
* Result: Pass

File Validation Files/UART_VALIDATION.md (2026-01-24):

# UART Validation

## Objective
To validate UART as the primary interface for observing firmware execution and system state during simulation.

## Configuration
* UART configured as per firmware settings
* Connected to Proteus Virtual Terminal

## Validation Performed
* Startup message confirmed firmware execution
* UART output used to verify system state transitions
* UART remained stable throughout simulation

## Observations
* UART output was event-driven
* No continuous logging during normal operation
* Output provided sufficient visibility for validation

## Conclusion
UART communication functioned reliably and served as an effective
debug and observation interface during simulation.

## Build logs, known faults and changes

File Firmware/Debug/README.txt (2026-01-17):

# Debug Module

This folder is reserved for firmware debug utilities such as:

- UART-based logging
- Diagnostic command handlers
- Manufacturing test hooks
- Temporary instrumentation

In the current firmware version:
- Debug output is intentionally minimal
- UART is used only for control commands
- No continuous logging is enabled to reduce overhead

This folder exists to preserve a clean firmware architecture
and to allow future debug expansion without restructuring.

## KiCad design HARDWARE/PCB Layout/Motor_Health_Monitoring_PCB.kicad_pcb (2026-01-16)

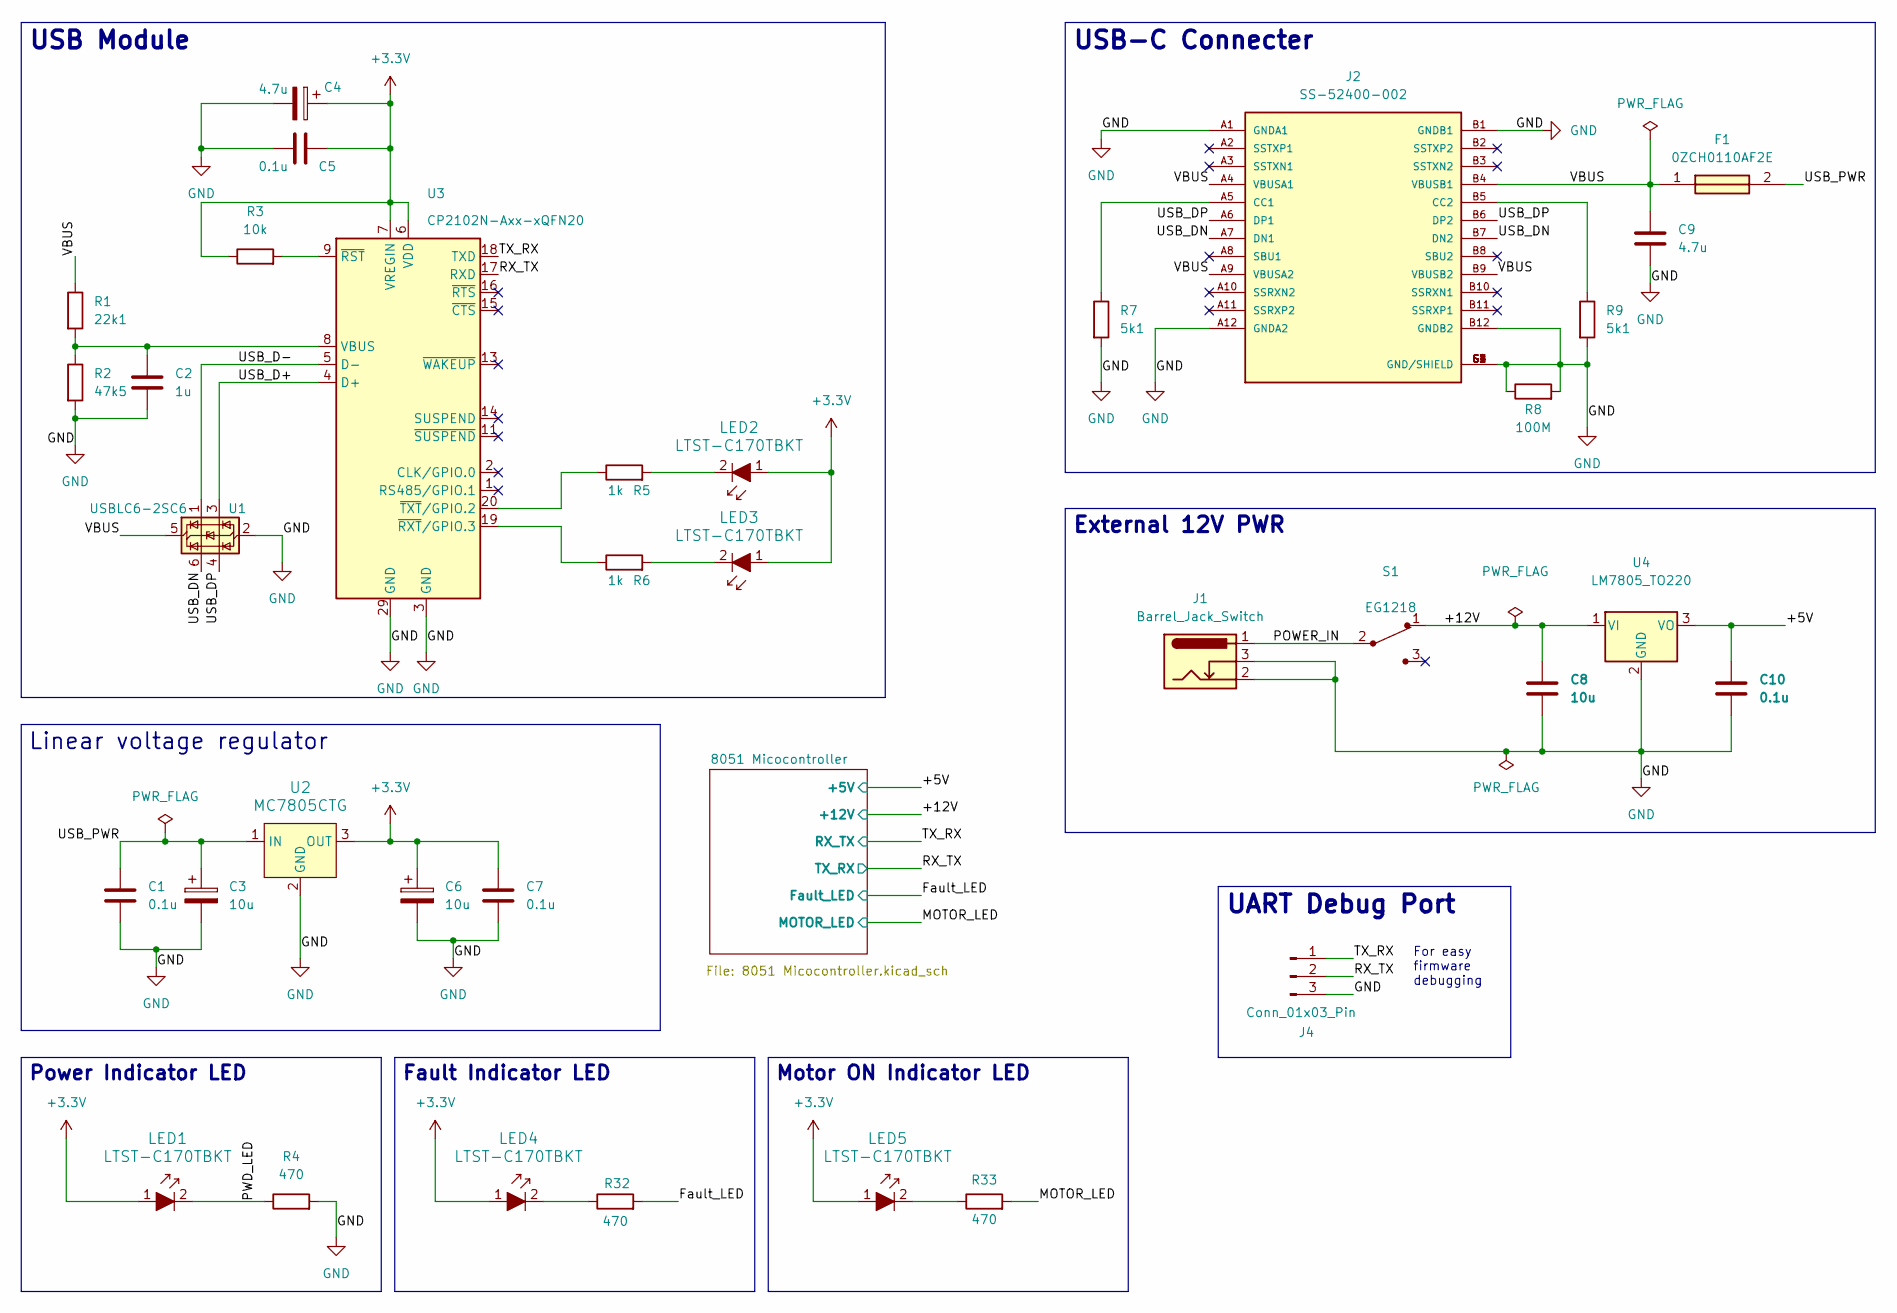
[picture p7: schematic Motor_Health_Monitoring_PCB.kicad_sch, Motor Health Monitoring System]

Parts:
C1, C5, C7: 0.1u; C_0805_2012Metric
C2: 1u; C_0805_2012Metric
C3, C6: 10u; T491A
C4: 4.7u; T491A
C8: 10u; C_Disc_D5.0mm_W2.5mm_P2.50mm
C9: 4.7u; C_0805_2012Metric
C10: 0.1u; C_Disc_D5.0mm_W2.5mm_P2.50mm
F1: 0ZCH0110AF2E; FUSC3226X100N; Manufacturer_Part_Number 0ZCH0110AF2E
J1: Barrel_Jack_Switch; BarrelJack_Horizontal
J2: SS-52400-002; BELFUSE_SS-52400-002; PARTREV A0
J4: Conn_01x03_Pin; PinHeader_1x03_P2.54mm_Vertical
LED1, LED2, LED3, LED4, LED5: LTST-C170TBKT; LED_0805_2012Metric_Pad1.15x1.40mm_HandSolder; MPN LTST-C170TBKT; Digi-Key_PN 160-1579-1-ND
R1: 22k1; R_0805_2012Metric
R2: 47k5; R_0805_2012Metric
R3: 10k; R_0805_2012Metric
R4, R32, R33: 470; R_0805_2012Metric
R5, R6: 1k; R_0805_2012Metric
R7, R9: 5k1; R_0805_2012Metric
R8: 100M; R_0805_2012Metric
S1: EG1218; Switch_Slide_11.6x4mm_EG1218; MPN EG1218; Digi-Key_PN EG1903-ND
U1: USBLC6-2SC6; SOT-23-6
U2: MC7805CTG; TO-220-3; MPN MC7805CTG; Digi-Key_PN MC7805CTGOS-ND
U3: CP2102N-Axx-xQFN20; QFN50P500X500X100-29N
U4: LM7805_TO220; TO-220-3_Vertical

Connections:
+3.3V: C4.1, C5.2, C6.1, C7.1, LED1.1, LED2.1, LED3.1, LED4.1, LED5.1, R3.1, U2.3 (OUT), U3.6 (VDD), U3.7 (VREGIN)
/+5V: C10.1, U4.3 (VO); also elsewhere on the board
/+12V: C8.1, S1.1, U4.1 (VI); also elsewhere on the board
/Fault_LED: R32.2; also elsewhere on the board
/MOTOR_LED: R33.2; also elsewhere on the board
/POWER_IN: J1.1, S1.2
/PWD_LED: LED1.2, R4.1
/RX_TX: J4.2, U3.17 (RXD); also elsewhere on the board
/TX_RX: J4.1, U3.18 (TXD); also elsewhere on the board
/USB_D+: U1.3 (I/O2), U3.4 (D+)
/USB_D-: U1.1 (I/O1), U3.5 (D-)
/USB_DN: J2.A7 (DN1), J2.B7 (DN2), U1.6 (I/O1)
/USB_DP: J2.A6 (DP1), J2.B6 (DP2), U1.4 (I/O2)
/USB_PWR: C1.1, C3.1, F1.2, U2.1 (IN)
/VBUS: C9.1, F1.1, J2.A4 (VBUSA1), J2.A9 (VBUSA2), J2.B4 (VBUSB1), J2.B9 (VBUSB2), R1.1, U1.5 (VBUS)
GND: C1.2, C2.2, C3.2, C4.2, C5.1, C6.2, C7.2, C8.2, C9.2, C10.2, J1.2, J1.3, J2.A1 (GNDA1), J2.A12 (GNDA2), J2.B1 (GNDB1), J2.B12 (GNDB2), J2.G1 (GND/SHIELD), J2.G2 (GND/SHIELD), J2.G3 (GND/SHIELD), J2.G4 (GND/SHIELD), J2.S1 (GND/SHIELD), J2.S2 (GND/SHIELD), J2.S3 (GND/SHIELD), J2.S4 (GND/SHIELD), J4.3, R2.2, R4.2, R7.2, R8.1, R8.2, R9.2, U1.2 (GND), U2.2 (GND), U3.3 (GND), U3.12 (GND), U3.21 (GND), U3.29 (GND), U4.2 (GND); also elsewhere on the board
unnamed: J2.A5 (CC1), R7.1
unnamed: J2.B5 (CC2), R9.1
unnamed: LED2.2, R5.2
unnamed: LED3.2, R6.2
unnamed: LED4.2, R32.1
unnamed: LED5.2, R33.1
unnamed: C2.1, R1.2, R2.1, U3.8 (VBUS)
unnamed: R3.2, U3.9 (~RST)
unnamed: R6.1, U3.19 (~RXT/GPIO.3)
unnamed: R5.1, U3.20 (~TXT/GPIO.2)

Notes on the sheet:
For easy firmware debugging
Power Indicator LED
Motor ON Indicator LED
Fault Indicator LED
USB Module
USB-C Connecter
External 12V PWR
UART Debug Port
Linear voltage regulator

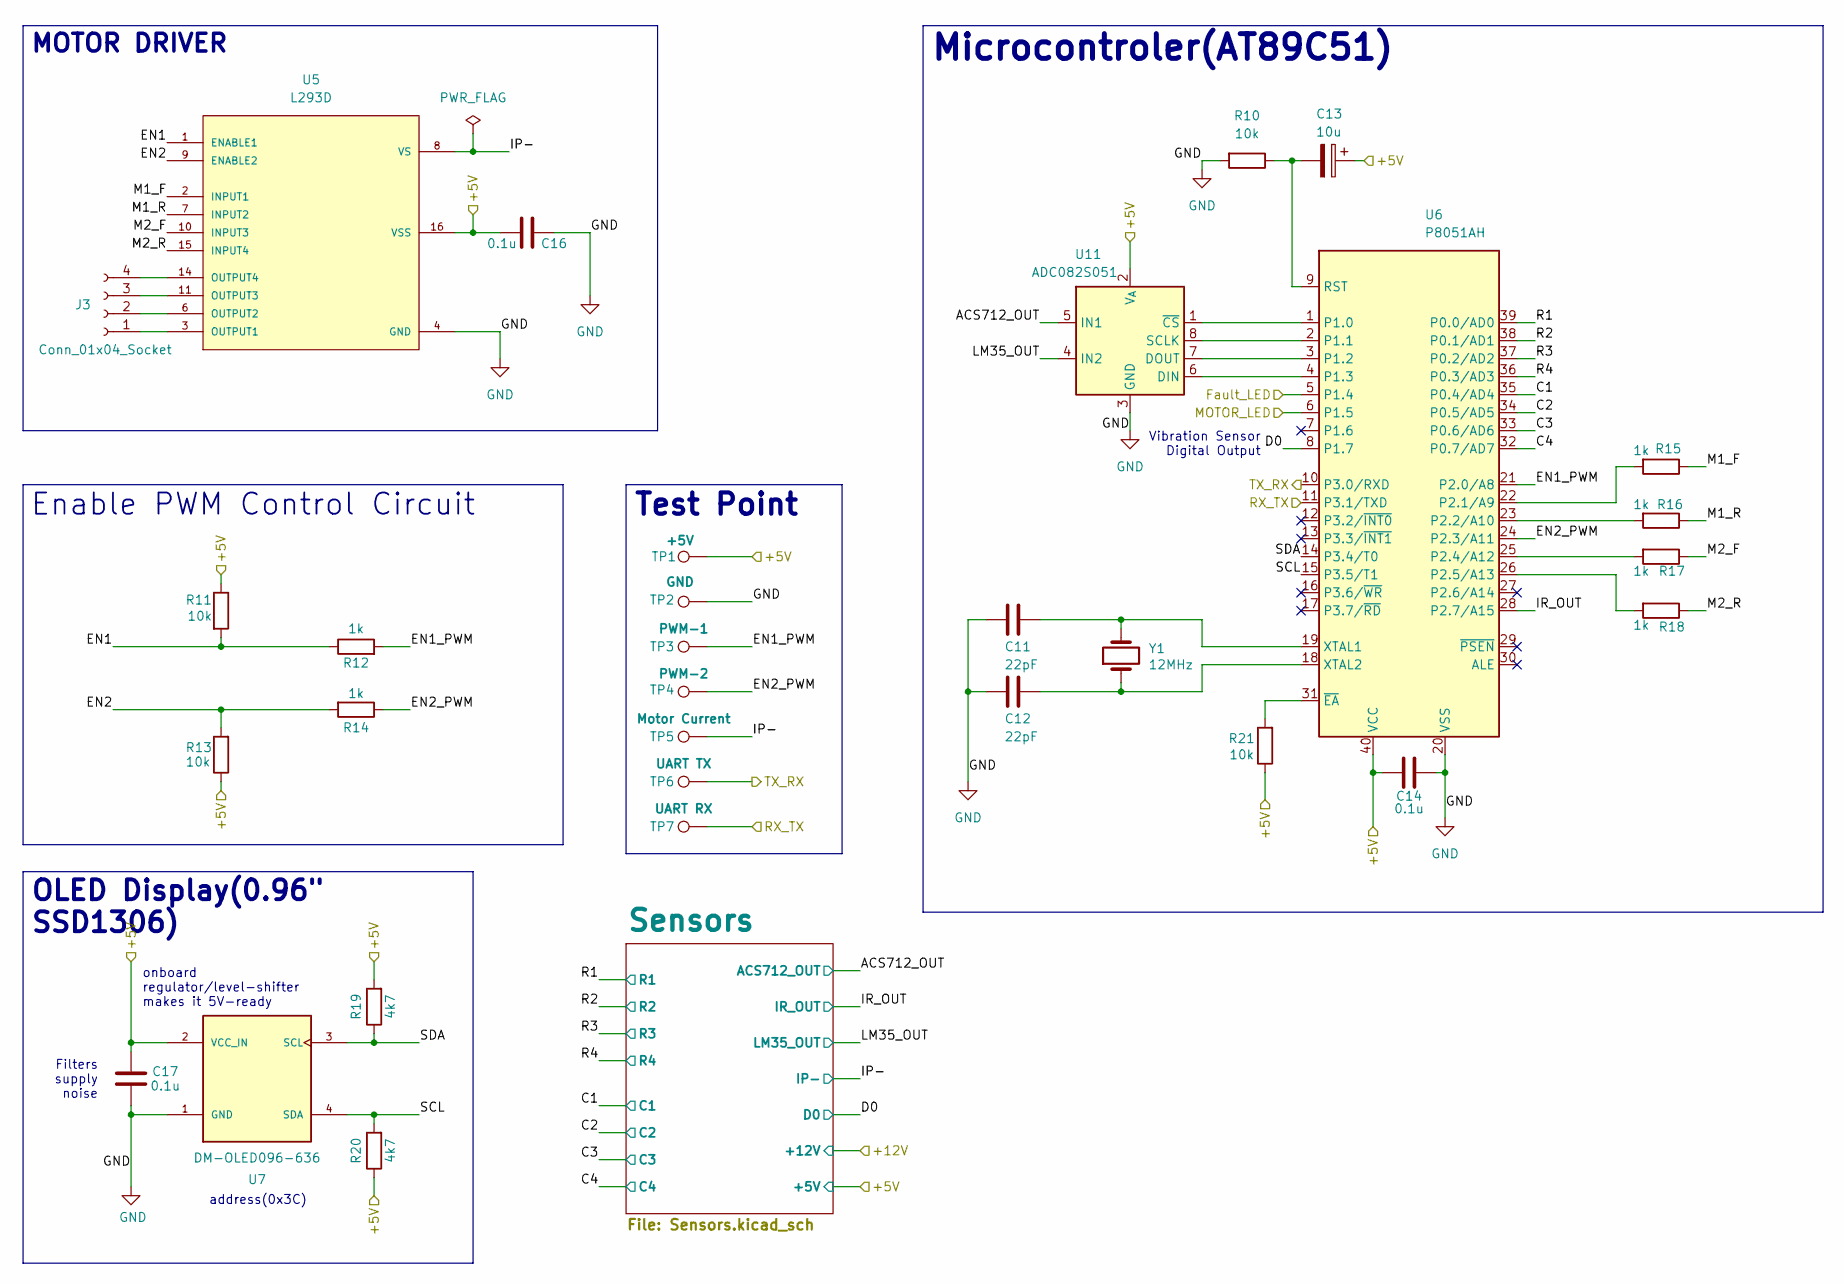
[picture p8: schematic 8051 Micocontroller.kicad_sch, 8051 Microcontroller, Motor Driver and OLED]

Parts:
C11, C12: 22pF; C_0805_2012Metric
C13: 10u; C_0805_2012Metric
C14, C16, C17: 0.1u; C_0805_2012Metric
J3: Conn_01x04_Socket; TerminalBlock_Phoenix_PT-1,5-4-5.0-H_1x04_P5.00mm_Horizontal
R10, R11, R13, R21: 10k; R_0805_2012Metric
R12, R14, R15, R16, R17, R18: 1k; R_0805_2012Metric
R19, R20: 4k7; R_0805_2012Metric
TP1: +5V; TestPoint_Pad_D2.0mm
TP2: GND; TestPoint_Pad_D2.0mm
TP3: PWM-1; TestPoint_Pad_D2.0mm
TP4: PWM-2; TestPoint_Pad_D2.0mm
TP5: Motor Current; TestPoint_Pad_D2.0mm
TP6: UART TX; TestPoint_Pad_D2.0mm
TP7: UART RX; TestPoint_Pad_D2.0mm
U5: L293D; DIP880W50P254L2000H510Q16
U6: P8051AH; DIP-40_W15.24mm
U7: DM-OLED096-636; MODULE_DM-OLED096-636; PARTREV 2018-09-10
U11: ADC082S051; VSSOP-8_3x3mm_P0.65mm
Y1: 12MHz; Crystal_SMD_5032-2Pin_5.0x3.2mm_HandSoldering

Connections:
/8051 Micocontroller/ACS712_OUT: U11.5 (IN1); also elsewhere on the board
/8051 Micocontroller/C1: U6.35 (P0.4/AD4); also elsewhere on the board
/8051 Micocontroller/C2: U6.34 (P0.5/AD5); also elsewhere on the board
/8051 Micocontroller/C3: U6.33 (P0.6/AD6); also elsewhere on the board
/8051 Micocontroller/C4: U6.32 (P0.7/AD7); also elsewhere on the board
/8051 Micocontroller/D0: U6.8 (P1.7); also elsewhere on the board
/8051 Micocontroller/EN1: R11.2, R12.1, U5.1 (ENABLE1)
/8051 Micocontroller/EN1_PWM: R12.2, TP3.1, U6.21 (P2.0/A8)
/8051 Micocontroller/EN2: R13.2, R14.2, U5.9 (ENABLE2)
/8051 Micocontroller/EN2_PWM: R14.1, TP4.1, U6.24 (P2.3/A11)
/8051 Micocontroller/IP-: TP5.1, U5.8 (VS); also elsewhere on the board
/8051 Micocontroller/IR_OUT: U6.28 (P2.7/A15); also elsewhere on the board
/8051 Micocontroller/LM35_OUT: U11.4 (IN2); also elsewhere on the board
/8051 Micocontroller/M1_F: R15.1, U5.2 (INPUT1)
/8051 Micocontroller/M1_R: R16.1, U5.7 (INPUT2)
/8051 Micocontroller/M2_F: R17.1, U5.10 (INPUT3)
/8051 Micocontroller/M2_R: R18.1, U5.15 (INPUT4)
/8051 Micocontroller/R1: U6.39 (P0.0/AD0); also elsewhere on the board
/8051 Micocontroller/R2: U6.38 (P0.1/AD1); also elsewhere on the board
/8051 Micocontroller/R3: U6.37 (P0.2/AD2); also elsewhere on the board
/8051 Micocontroller/R4: U6.36 (P0.3/AD3); also elsewhere on the board
/8051 Micocontroller/SCL: R20.2, U6.15 (P3.5/T1), U7.4 (SDA)
/8051 Micocontroller/SDA: R19.1, U6.14 (P3.4/T0), U7.3 (SCL)
/+5V: C13.1, C14.1, C16.1, C17.2, R11.1, R13.1, R19.2, R20.1, R21.1, TP1.1, U5.16 (VSS), U6.40 (VCC), U7.2 (VCC_IN), U11.2 (V_{A}); also elsewhere on the board
/Fault_LED: U6.5 (P1.4); also elsewhere on the board
/MOTOR_LED: U6.6 (P1.5); also elsewhere on the board
/RX_TX: TP6.1, U6.10 (P3.0/RXD); also elsewhere on the board
/TX_RX: TP7.1, U6.11 (P3.1/TXD); also elsewhere on the board
GND: C11.2, C12.2, C14.2, C16.2, C17.1, R10.2, TP2.1, U5.4 (GND), U5.5 (GND), U5.12 (GND), U5.13 (GND), U6.20 (VSS), U7.1 (GND), U11.3 (GND); also elsewhere on the board
unnamed: J3.1, U5.3 (OUTPUT1)
unnamed: J3.2, U5.6 (OUTPUT2)
unnamed: J3.3, U5.11 (OUTPUT3)
unnamed: J3.4, U5.14 (OUTPUT4)
unnamed: R15.2, U6.22 (P2.1/A9)
unnamed: R16.2, U6.23 (P2.2/A10)
unnamed: R17.2, U6.25 (P2.4/A12)
unnamed: R18.2, U6.26 (P2.5/A13)
unnamed: C13.2, R10.1, U6.9 (RST)
unnamed: C11.1, U6.19 (XTAL1), Y1.2
unnamed: C12.1, U6.18 (XTAL2), Y1.1
unnamed: R21.2, U6.31 (~EA)
unnamed: U6.4 (P1.3), U11.6 (DIN)
unnamed: U6.3 (P1.2), U11.7 (DOUT)
unnamed: U6.2 (P1.1), U11.8 (SCLK)
unnamed: U6.1 (P1.0), U11.1 (~CS)

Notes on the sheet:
onboard regulator/level-shifter makes it 5V-ready
address(0x3C)
Vibration Sensor Digital Output
Filters supply noise
Test Point
MOTOR DRIVER
Microcontroler(AT89C51)
Enable PWM Control Circuit
OLED Display(0.96" SSD1306)

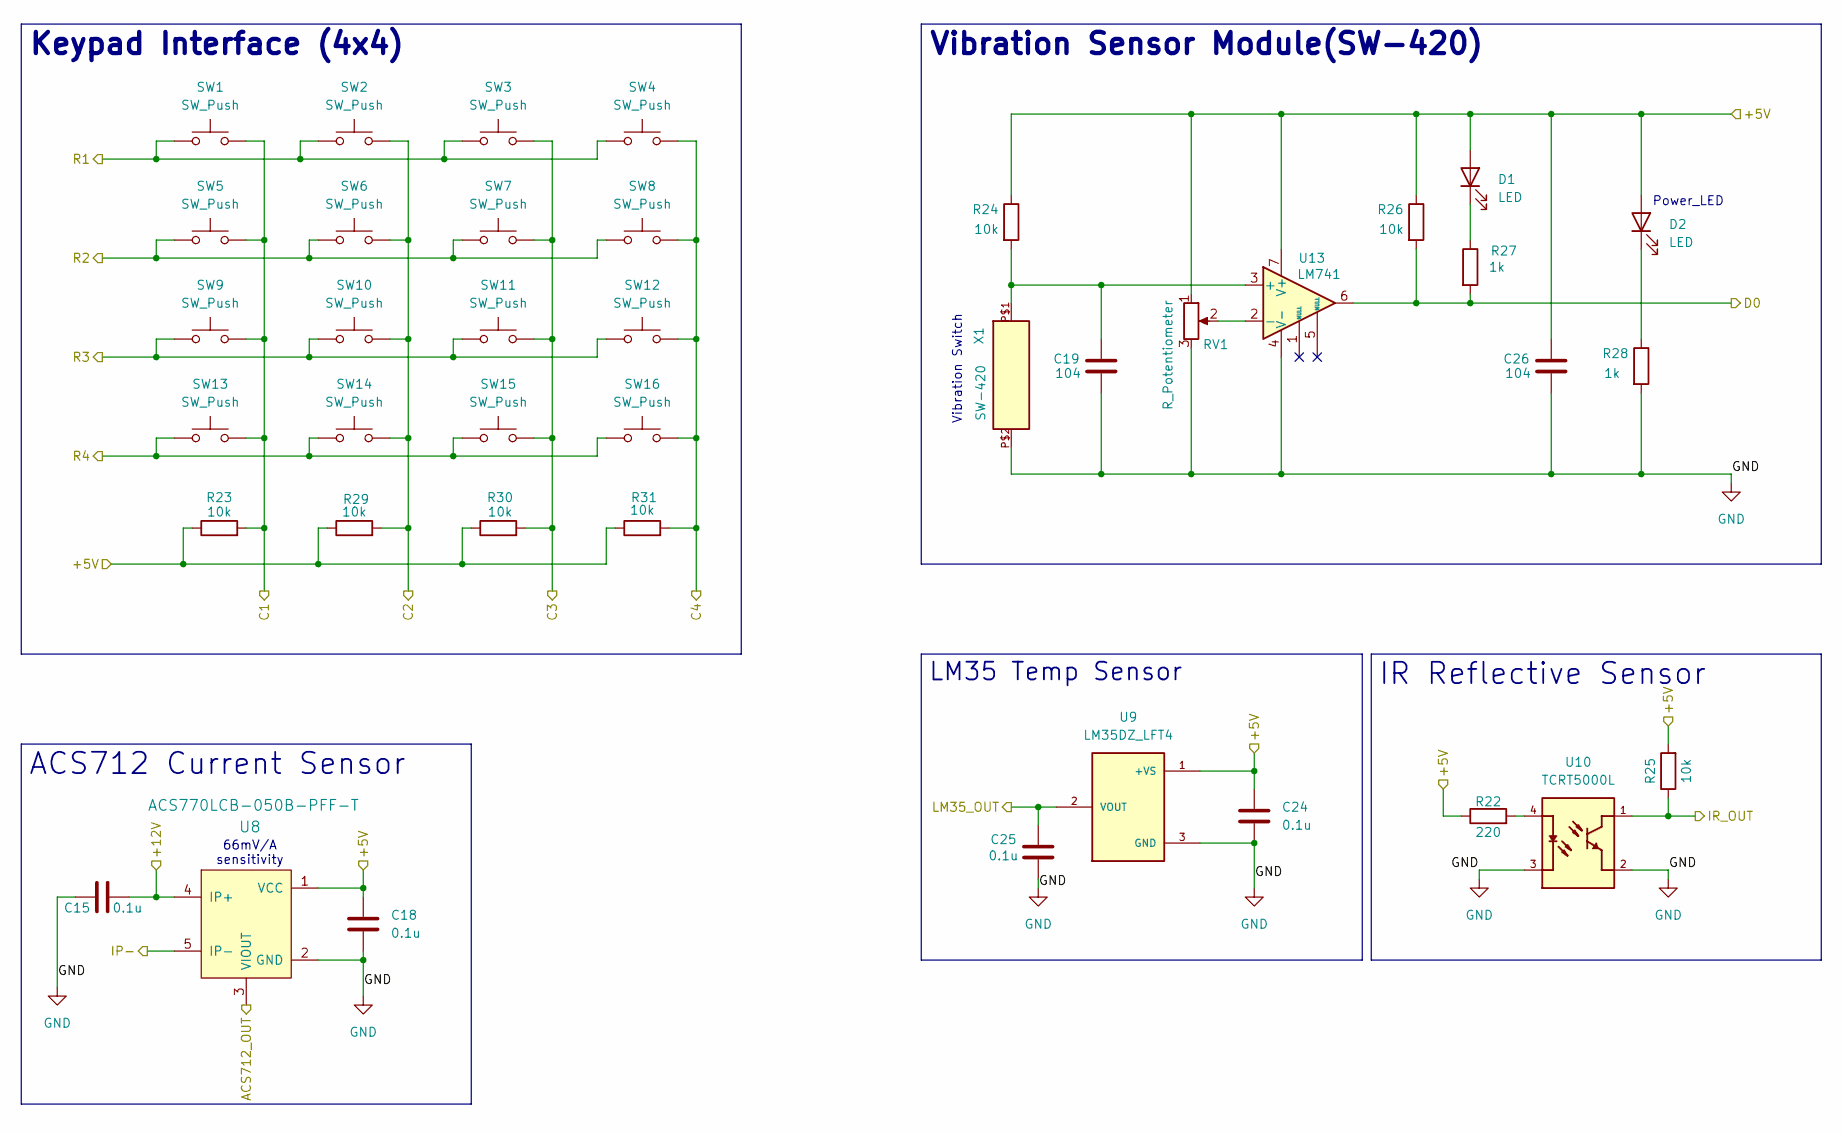
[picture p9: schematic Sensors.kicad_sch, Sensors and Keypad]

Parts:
C15, C18, C24, C25: 0.1u; C_0805_2012Metric
C19, C26: 104; C_0805_2012Metric
D1, D2: LED; LED_0805_2012Metric_Pad1.15x1.40mm_HandSolder
R22: 220; R_0805_2012Metric
R23, R24, R25, R26, R29, R30, R31: 10k; R_0805_2012Metric
R27, R28: 1k; R_0805_2012Metric
RV1: R_Potentiometer; Potentiometer_Bourns_3266Y_Vertical
SW1, SW2, SW3, SW4, SW5, SW6, SW7, SW8, SW9, SW10, SW11, SW12, SW13, SW14, SW15, SW16: SW_Push; SW_PUSH_1P1T_6x3.5mm_H5.0_APEM_MJTP1250
U8: ACS770LCB-050B-PFF-T; CB-5_Formed_Leads; MPN ACS770LCB-050B-PFF-T; Digi-Key_PN 620-1541-5-ND
U9: LM35DZ_LFT4; IC_LM35DZ_LFT4; PARTREV H
U10: TCRT5000L; XDCR_TCRT5000L
U13: LM741; DIP794W45P254L959H508Q8
X1: SW-420

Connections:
/8051 Micocontroller/ACS712_OUT: U8.3 (VIOUT); also elsewhere on the board
/8051 Micocontroller/C1: R23.2, SW1.2, SW5.2, SW9.2, SW13.2; also elsewhere on the board
/8051 Micocontroller/C2: R29.2, SW2.2, SW6.2, SW10.2, SW14.2; also elsewhere on the board
/8051 Micocontroller/C3: R30.2, SW3.2, SW7.2, SW11.2, SW15.2; also elsewhere on the board
/8051 Micocontroller/C4: R31.2, SW4.2, SW8.2, SW12.2, SW16.2; also elsewhere on the board
/8051 Micocontroller/D0: R26.2, R27.2, U13.6; also elsewhere on the board
/8051 Micocontroller/IP-: U8.5 (IP-); also elsewhere on the board
/8051 Micocontroller/IR_OUT: R25.1, U10.1; also elsewhere on the board
/8051 Micocontroller/LM35_OUT: C25.1, U9.2 (VOUT); also elsewhere on the board
/8051 Micocontroller/R1: SW1.1, SW2.1, SW3.1, SW4.1; also elsewhere on the board
/8051 Micocontroller/R2: SW5.1, SW6.1, SW7.1, SW8.1; also elsewhere on the board
/8051 Micocontroller/R3: SW9.1, SW10.1, SW11.1, SW12.1; also elsewhere on the board
/8051 Micocontroller/R4: SW13.1, SW14.1, SW15.1, SW16.1; also elsewhere on the board
/+5V: C18.1, C24.1, C26.1, D1.2 (A), D2.2 (A), R22.1, R23.1, R24.1, R25.2, R26.1, R29.1, R30.1, R31.1, RV1.1, U8.1 (VCC), U9.1 (+VS), U13.7 (V+); also elsewhere on the board
/+12V: C15.1, U8.4 (IP+); also elsewhere on the board
GND: C15.2, C18.2, C19.2, C24.2, C25.2, C26.2, R28.2, RV1.3, U8.2 (GND), U9.3 (GND), U10.2, U10.3, U13.4 (V-), X1.P$2; also elsewhere on the board
unnamed: D1.1 (K), R27.1
unnamed: D2.1 (K), R28.1
unnamed: R22.2, U10.4
unnamed: C19.1, R24.2, U13.3 (+), X1.P$1
unnamed: RV1.2, U13.2 (-)

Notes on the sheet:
Vibration Switch
Power_LED
66mV/A sensitivity
ACS712 Current Sensor
Vibration Sensor Module(SW-420)
IR Reflective Sensor
LM35 Temp Sensor
Keypad Interface (4x4)

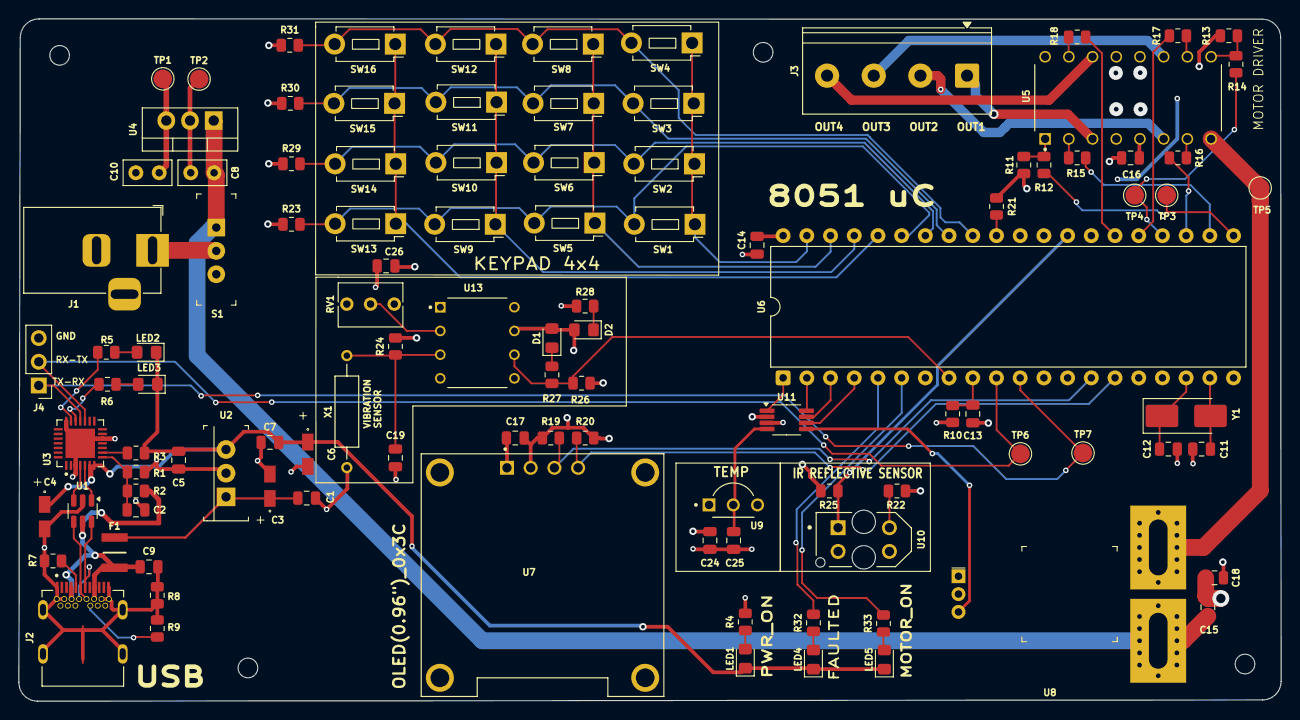
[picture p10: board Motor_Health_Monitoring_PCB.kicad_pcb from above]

Board: 4 copper layers, 135.2 x 73.1 mm, 106 parts (0 on the bottom side), 70 nets.

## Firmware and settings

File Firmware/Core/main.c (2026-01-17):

#include "system.h"
#include "uart.h"
#include "gpio.h"
#include "timer.h"
#include "adc.h"
#include "pwm.h"
#include "keypad.h"
#include "uart_rx.h"
#include "fault_manager.h"
#include "motor_state.h"
#include "uart_cmd.h"
#include "oled.h"
#include "pin_config.h"
#include "filter.h"

void main(void)
{
    unsigned long last = 0;
	  unsigned int adc_current = 0;   //Raw ADC Values
	  unsigned int adc_temp = 0;
	
	  float v_current = 0.0f;        //Converted Voltages
    float v_temp    = 0.0f;
	
	  float current_A = 0.0f;       //Final physical values
    float temperature_C = 0.0f;

    System_Init();
    UART_Init();
    GPIO_Init();
    Timer0_Init();
    ADC_Init();
    Fault_Init();
    MotorState_Init();
    PWM_Init();
    UART_RX_Init();
    Keypad_Init();
    OLED_Init();
          	
    UART_SendString("ADC TEST START\r\n");

    while (1)
    {
        unsigned char key = Keypad_GetKey();
if (key)
{
        while (Keypad_GetKey()); // wait for release
}

	UART_RX_Process();
			  
    {
   unsigned char key = Keypad_GetKey();

if (key)
{
    if (!Fault_IsActive())
    {
        switch (key)
        {
            case 1:   // START
                MotorState_SetRun();
                break;

            case 2:   // STOP
                MotorState_SetIdle();
                break;

            case 3:   // RESET FAULT
                MotorState_ResetFault();
                break;

            case 4:   // EMERGENCY STOP
                MotorState_SetIdle();
                break;

            case 5:   // PWM +5
                PWM_AdjustSigned(+5);
                break;

            case 6:   // PWM -5
                PWM_AdjustSigned(-5);
                break;

            case 7:   // PWM +10
                PWM_AdjustSigned(+10);
                break;

            case 8:   // PWM -10
                PWM_AdjustSigned(-10);
                break;

            case 9:   // 25%
                PWM_SetDuty(25);
                break;

            case 10:  // 50%
                PWM_SetDuty(50);
                break;

            case 11:  // 75%
                PWM_SetDuty(75);
                break;

            case 12:  // 100%
                PWM_SetDuty(100);
                break;

            default:
                break;
        }
    }
    else
    {
        // FAULT active → only RESET allowed
        if (key == 3)
        {
            MotorState_ResetFault();
        }
    }

    // Wait for key release (debounce)
    while (Keypad_GetKey());
}

    } 
    
	if (UART_RX_CommandReady())
{
    UART_CMD_Process(UART_RX_GetCommand());
}
		
        if (millis() - last >= 1000)
        {
            last = millis();
					   
					  adc_current = ADC_Read(ADC_CH_ACS712);
            adc_temp    = ADC_Read(ADC_CH_LM35);
         
            v_current = adc_to_voltage(adc_current); //ADC -> Voltage
            v_temp    = adc_to_voltage(adc_temp);
					
					  current_A      = voltage_to_current(v_current); //Voltage-> Physical Units
            temperature_C  = voltage_to_temperature(v_temp);
					
					  Fault_Check(current_A, temperature_C);
	    OLED_Clear();
            OLED_SetCursor(0, 0);
            OLED_Print("SYSTEM OK");


				
	/*  OLED_Clear();

            //Line 1 
            OLED_SetCursor(0, 0);
            OLED_Print("STATE:");
            if (MotorState_Get() == MOTOR_RUN)
               OLED_Print("RUN");
            else if (MotorState_Get() == MOTOR_FAULT)
               OLED_Print("FAULT");
            else
               OLED_Print("IDLE");

            //Line 2 
            OLED_SetCursor(2, 0);
            OLED_Print("PWM:");
            //show duty roughly
            OLED_Print("XX%");   // (numeric formatting can be refined)

            //Line 3
            OLED_SetCursor(4, 0);
            OLED_Print("I:");
            OLED_Print("A");

            //Line 4 
            OLED_SetCursor(6, 0);
            OLED_Print("T:");
            OLED_Print("C"); */

					
					  //STATE OVERRIDE BY FAULT
         if (Fault_IsActive())
         {
              MotorState_SetFault();
         }  
        }
				 if (Fault_IsActive())
           {
                  // placeholder
           }

    }
}

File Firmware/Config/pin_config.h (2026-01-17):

#ifndef PIN_CONFIG_H
#define PIN_CONFIG_H

#include <8051.h>

// LED pins (from schematic)
#define LED_FAULT  P1_4
#define LED_MOTOR  P1_5

// ADC pins (U11)
#define CS    P1_0
#define CLK   P1_1
#define DIN   P1_2
#define DOUT  P1_3

// Motor PWM enable pins
#define EN1_PWM  P2_0
#define EN2_PWM  P2_3

// Keypad rows (outputs)
#define KP_R1  P0_0
#define KP_R2  P0_1
#define KP_R3  P0_2
#define KP_R4  P0_3

// Keypad columns (inputs, pull-up)
#define KP_C1  P0_4
#define KP_C2  P0_5
#define KP_C3  P0_6
#define KP_C4  P0_7

// OLED I2C pins
#define OLED_SCL  P3_4
#define OLED_SDA  P3_5

#endif

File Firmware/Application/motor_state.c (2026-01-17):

#include "motor_state.h"
#include "pin_config.h"
#include "fault_manager.h"

static motor_state_t motor_state = MOTOR_IDLE;

void MotorState_Init(void)
{
    motor_state = MOTOR_IDLE;

    // IDLE = PWM 0%
    EN1_PWM = 0;
    EN2_PWM = 0;
}

void MotorState_SetRun(void)
{
    if (!Fault_IsActive())
    {
        motor_state = MOTOR_RUN;
        // PWM duty will be applied elsewhere (UART command)
    }
}

void MotorState_SetIdle(void)
{
    motor_state = MOTOR_IDLE;
    EN1_PWM = 0;
    EN2_PWM = 0;
}

void MotorState_SetFault(void)
{
    motor_state = MOTOR_FAULT;
    EN1_PWM = 0;
    EN2_PWM = 0;
}

void MotorState_ResetFault(void)
{
    // Clear fault latch and go to IDLE
    Fault_Init();
    motor_state = MOTOR_IDLE;
    EN1_PWM = 0;
    EN2_PWM = 0;
}

motor_state_t MotorState_Get(void)
{
    return motor_state;
}

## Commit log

2026-01-16 Initial hardware project upload
    [8051 Micocontroller.kicad_sch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]
2026-01-16 Cleanup: remove KiCad backups and cache files
2026-01-16 Add .gitignore for Kicad project
2026-01-16 Ignore KiCad runtime and cache files
2026-01-17 Add initial firmware architecture and hardware BOM
    [Motor_Health_Monitoring_PCB.xls]
2026-01-24 Validation files added and changes saved
    [8051 Micocontroller.kicad_sch]
2026-01-24 Fix formatting of error responses in uart_protocol.md
2026-01-24 Add Schematic_png.md with image reference
